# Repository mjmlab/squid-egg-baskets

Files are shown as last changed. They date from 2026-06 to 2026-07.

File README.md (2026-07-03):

# Mandel Lab Squid Egg Baskets

### ⚠️ Caveat: We have done minimal testing with the baskets, and will update in the future when we do more.

| Baskets in a tank | Baskets in a tank, one removed to show the pores |
|---|---|
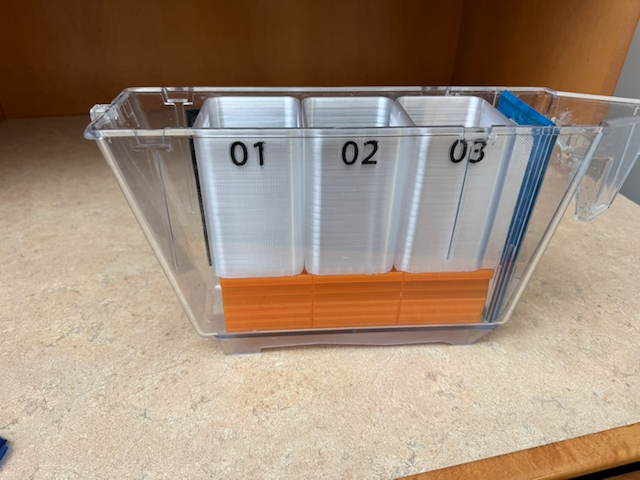
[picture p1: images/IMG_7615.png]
Baskets in the tank
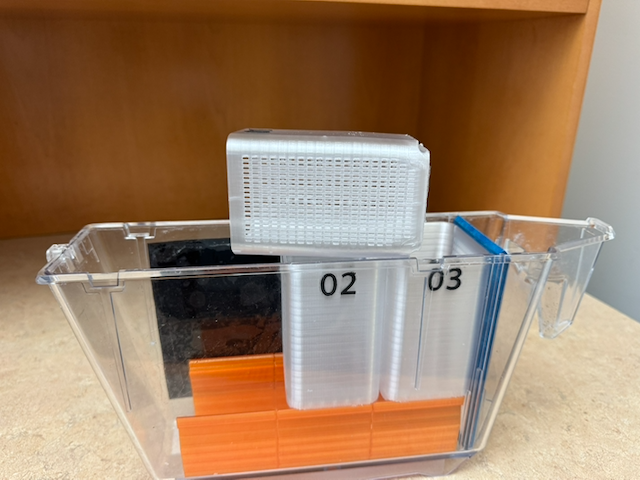
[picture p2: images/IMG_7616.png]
Baskets in the tank, one removed to show the pores
|  |  |

## Design

The lab commissioned [Jesse Darley](https://making.engr.wisc.edu/staff/darley-jesse/) to design baskets for *Euprymna scolopes* and *Euprymna berryi* egg/embryo clutches. The current designs are listed on this site and can be enjoyed by others for non-commercial uses.

Here are the parameters we employed/refined in the design:
- Baskets are to fit in an Iwaki `AQT2LT` 2 L tank fitted with an `AQT2LC` lid and `AQT2LF10` 1000 μm filter.
- Basket height should allow the tank lid to close, to limit evaporation and salt build-up. We adjusted the initial height of the baskets to be as close to the lid as possible so that hatchlings would not surf out of the baskets if the tank was tipped while moving it off the system gutter, or to/from a counter.
- Ideal is to have up to 3 baskets per tank, but want it to be feasible to have only 1 or 2 baskets in place.
- Need to be able to see hatchlings through the tank and be able to remove them readily, so want to use transparent. *Note: The transparent PETG we are currently using allows us to see a hint of the squid but it ends up more of a translucent white than as fully transparent.*
- Water flow will be from front to back, and should be maximal through the basket (i.e., no/minimal trough in the middle where the clutches will sit).
- Slots were balanced to be small enough that squid would not pass through, large enough that water would flow through readily, and large enough to be reliably 3D printed on available instrumentation (Bambu printers).
- Plastic needs to be non-toxic for the animals. Using PETG.
- Baskets should be numbered to reduce/remove the need for us to write on the baskets. We can then record clutch numbers and connect those numbers to the corresponding baskets.

Through testing, we further modified the baskets as follows:
- The side of the basket is vertical near its top—rather than matching the side of the tank—to allow room for the water to flow around the basket and limit surface tension near the top of the basket that could carry squid hatchlings out of the baskets.
- The platform was printed as a separate device from earlier prototypes. This offered two substantial benefits. First, it allowed the baskets to be a standardized shape for mass printing (rather than having a stand attached). Second, the platform design enables mounting 1, 2, or 3 baskets in a tank. The platform designed by Jesse allows users to readily snap in/out baskets without disrupting neighboring baskets (especially important if those baskets are filled with eggs!).
- The platform design additionally offers another advantage: It can fit an air stone if desired.

## Assembly Notes

- Number labels press into recess in baskets.
- Squeeze the platform to break weak connection between sections. These sections let the platform sections flex independently to add or remove individual baskets.

## 3D Printing

#### Download files:

[3D Printing Files](3d-printing-files-2026-06-25)

#### Printers used:

```
Platform: Bambu X1-Carbon
Baskets and Number Labels: Bambu H2D
```

#### Material/Color

```
Plastic: PETG
Basket color: transparent
Number color: black
Platform color: orange (had on hand)
```

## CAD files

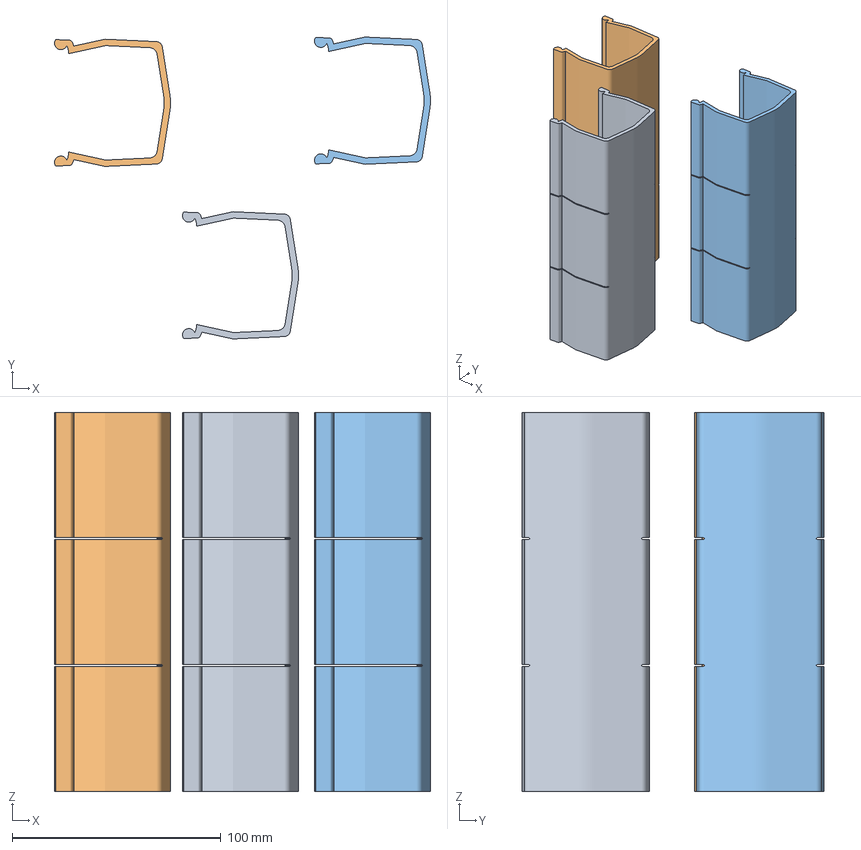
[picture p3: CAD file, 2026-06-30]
3d-printing-files-2026-06-25/platform-2026-06-17.3mf
180.2 x 144.7 x 181.7 mm
Platform 2026-06-17.stl x 3

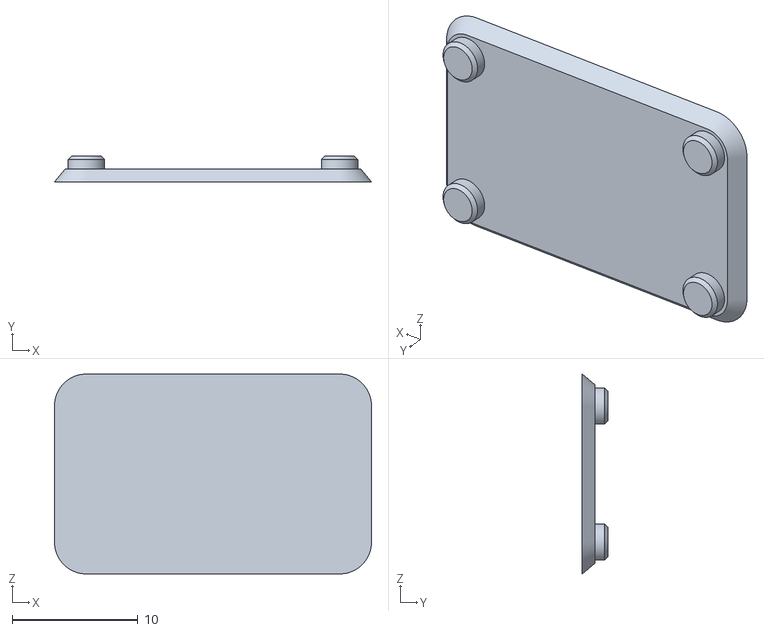
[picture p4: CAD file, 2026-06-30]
3d-printing-files-2026-06-25/number-plaque-with-007-offset-2026-06-23.stl
25.2 x 2.03 x 15.9

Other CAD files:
3d-printing-files-2026-06-25/platform-2026-06-17.stl

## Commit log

2026-06-30 First production egg baskets
    [number-plaque-with-007-offset-2026-06-23.stl, platform-2026-06-17.3mf, platform-2026-06-17.stl]
2026-07-03 Add 3D printer details
2026-07-03 Add Assembly Notes
